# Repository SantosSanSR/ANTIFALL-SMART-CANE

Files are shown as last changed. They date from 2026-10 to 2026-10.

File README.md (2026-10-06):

# AFSC — Anti-Fall Smart Cane

An ESP32-based assistive technology prototype exploring multisensor
event detection, local feedback, and remote notifications through Telegram.

Developed in the academic context of Bionic Engineering at
Universidad Popular Autónoma del Estado de Puebla (UPAEP), Puebla, Mexico.

**Project lead:** Santiago Alejandro Santos Rosas
**Status:** Academic prototype — validation pending

## Overview

AFSC integrates motion, impact, optical pulse sensing, and passive
infrared motion detection into a walking cane prototype.

The firmware combines sensor-trigger information using a state machine
that escalates from local audible and visual feedback to remote
Telegram notifications. A user acknowledgement button supports
alert cancellation.

The project explores embedded systems, physiological instrumentation,
assistive technology, and systems-engineering documentation.

Despite the project name, AFSC does not physically prevent falls.
It investigates the detection of possible events and notification
of a designated contact.

## Main features

- Acceleration and orientation monitoring using an MPU6050.
- Impact detection using three KY-031 modules.
- Experimental optical pulse estimation using a MAX30102.
- PIR-based motion/inactivity triggering.
- Multisensor trigger aggregation and escalating alert states.
- OLED display showing system state, trigger count, and sensor information.
- Audible feedback through a buzzer.
- Visual feedback through an LED indicator.
- Wi-Fi connectivity and Telegram notifications.
- User acknowledgement/cancellation button.
- Serial diagnostics and sensor initialization checks.

## Hardware

| Component | Quantity | Role |
|---|---:|---|
| ESP32-WROOM-32 development board | 1 | Processing and Wi-Fi communication |
| MPU6050 | 1 | Acceleration and orientation sensing |
| MAX30102 | 1 | Experimental optical pulse sensing |
| KY-031 | 3 | Impact-trigger inputs |
| HW-456 / SR505 mini PIR | 1 | Motion-trigger input |
| SSD1306 OLED, 128 × 64 | 1 | System feedback |
| Buzzer | 1 | Audible feedback |
| LED indicator | 1 | Visual feedback |
| Push button | 1 | User acknowledgement |
| Battery and power circuitry | As required | Portable power |
| Cane frame and wiring | As required | Mechanical integration |

Verify the electrical specifications of the actual modules before assembly.
The GPIO table below is a firmware mapping, not a complete wiring guide.

## Firmware GPIO mapping

| Signal | ESP32 GPIO |
|---|---:|
| Impact sensor 1 | 27 |
| Impact sensor 2 | 26 |
| Impact sensor 3 | 25 |
| Buzzer | 14 |
| Acknowledgement button | 2 |
| PIR input | 33 |
| LED indicator | 13 |
| I²C SDA | 21 |
| I²C SCL | 22 |

The button wiring and active logic level must be checked before use:
the design report contains inconsistent descriptions of the pull-up
configuration and pressed state.

## System architecture

```text
MPU6050 ────────────────┐
3 × KY-031 ────────────┤
MAX30102 ──────────────┼── ESP32 ── State machine ── OLED / LED / Buzzer
PIR motion input ──────┤                  │
Acknowledgement button┘                  └── Wi-Fi ── Telegram
```

### Trigger aggregation

The firmware aggregates four trigger categories:

1. Impact.
2. Motion/orientation-based possible fall event.
3. Optical pulse signal availability.
4. PIR-based absence of detected motion.

The three impact modules contribute to one impact category;
they are not counted as three independent alert categories.

| Active trigger categories | Firmware state |
|---:|---|
| 0 | `NORMAL` |
| 1 | `ALERT_1` |
| 2 | `ALERT_2` |
| 3 | `ALERT_3` |
| 4 | `CRITICO` |

Additional states include `CALIBRATING` and `CANCELLED`.

A high trigger count is a prototype classification rule.
It does not establish that a person has fallen or is experiencing
a medical emergency.

## Software dependencies

The firmware shown in the design report uses:

- Arduino framework with ESP32 board support.
- `Wire`
- `WiFi`
- `WiFiClientSecure`
- `UniversalTelegramBot`
- `MPU6050_tockn`
- `Adafruit_GFX`
- `Adafruit_SSD1306`
- `MAX30105` and `heartRate.h` from the SparkFun MAX3010x library.
- ESP32 system utilities through `esp_system.h`.

Dependency and board-package versions should be recorded after
a successful build. Third-party dependencies retain their own licenses.

## Getting started

1. Install Arduino IDE and ESP32 board support.
2. Install the required libraries and their dependencies.
3. Open the project firmware.
4. Review the wiring and verify module voltage compatibility.
5. Configure Wi-Fi and Telegram credentials locally.
6. Select the correct ESP32 board and serial port.
7. Compile and upload the firmware.
8. Open the Serial Monitor at 115200 baud.
9. Keep the device stationary during initialization and calibration.
10. Perform controlled bench tests before any demonstration.

Do not test falls by asking a person to fall.

### Credentials

Never commit real Wi-Fi passwords, Telegram bot tokens,
or personal chat identifiers.

For publication, replace embedded credentials with placeholders.
A recommended improvement is to move credentials into a local
`secrets.h` file and publish only `secrets.example.h`.

Creating these files alone does not change the firmware:
the sketch must be updated to include and use the local configuration.

## Validation status

The design report documents the architecture, firmware, and a test plan.
It does not establish quantified clinical or real-world performance.

Planned evaluation includes:

- Individual sensor checks.
- Controlled motion and impact simulations.
- State-machine transition testing.
- Acknowledgement-button testing.
- Telegram delivery and failure handling.
- Response-time measurement.
- Power consumption and battery-runtime testing.
- Mechanical integration checks.
- Repeatability and false-alert assessment.

Battery autonomy, detection accuracy, environmental resistance,
and notification latency must be treated as targets until measured
and supported by test records.

## Known limitations and review items

- Cane motion is not equivalent to body motion; dropping the cane
  may resemble a fall event.
- PIR activity is not a direct measurement of the user's mobility
  or consciousness.
- Optical pulse estimates depend on contact and signal quality.
- Loss of optical signal is not evidence of a cardiac emergency.
- The firmware does not demonstrate validated abnormal-heart-rate
  detection.
- Remote notifications depend on Wi-Fi, internet access, and Telegram.
- Blocking delays and network requests require latency evaluation.
- The report's firmware uses `client.setInsecure()`, disabling TLS
  certificate verification; this must be reviewed before deployment.
- The inactivity threshold differs between the report's test plan
  and the firmware.
- Button polarity and cancellation behavior require verification.
- An ultrasonic obstacle sensor is mentioned as a requirement,
  but is not implemented in the firmware shown in the report.
- No clinical validation, IP rating, or certified emergency-response
  performance is claimed.

## Documentation and demonstration

The project follows a PDR/CDR-style documentation process covering:

- Requirements.
- System architecture.
- Hardware selection.
- Firmware design.
- Integration.
- Test planning.
- Safety considerations.

Prototype demonstration:
[Watch the circuit demonstration](https://youtu.be/Oy1licVQWoQ)

## Safety notice

This is an academic and research prototype, not a clinically
validated medical device.

It must not be relied upon for diagnosis, treatment, fall prevention,
patient monitoring, or emergency response. It does not replace
a caregiver, certified assistive equipment, or emergency services.

## Authorship and acknowledgement

Project lead: Santiago Alejandro Santos Rosas.

When referencing this work, credit Santiago Alejandro Santos Rosas,
identify AFSC — Anti-Fall Smart Cane, and link to this repository.

Suggested acknowledgement:

> Based on AFSC — Anti-Fall Smart Cane, led by Santiago Alejandro
> Santos Rosas. Adaptations are the responsibility of their authors
> and do not imply endorsement by the original project lead.

Contributors and supervisors must also be credited for their actual
contributions. Project leadership does not, by itself, establish
exclusive ownership of every repository asset.

## Licensing

Original firmware is provided under the PolyForm Noncommercial
License 1.0.0. See `LICENSE`.

Original report text, photographs, and explanatory documentation
are provided under Creative Commons Attribution-NonCommercial
4.0 International. See `LICENSE-DOCUMENTATION.md`.

Third-party software and materials retain their original licenses.
Hardware manufacturing and patent rights are not granted by the
documentation license.

Commercial permissions outside these licenses require a separate
written agreement from the relevant rights holder(s).

These are source-available, noncommercial terms; this project is not
described as open source.

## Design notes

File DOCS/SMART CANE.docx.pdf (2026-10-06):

### AFSC: ANTI-FALL SMART CANE

Critical Design Document

IET400_CDR_V1.
0
Revision 0.1

File Name: IET400_CDR_V1.0 Revision: 0.1
Effective
Date:05/08/25

Universidad Popular Autónoma del Estado de Puebla Puebla, México. 72410

## Critical Design Document

# Critical Design Document

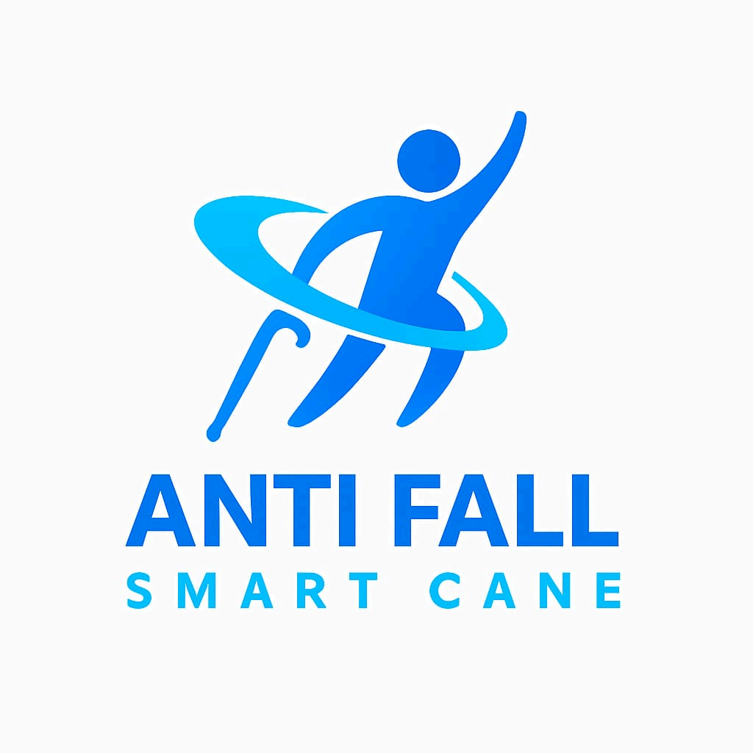
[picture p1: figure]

### AFSC: ANTI FALL SMART CANE

Critical Design Document

IET400_CDR_V1.0
Revision 0.1
Owners Document | E-Mail | Position
Leader & Owner Name | santiagoalejandro.santos @upaep.edu.mx | Project Leader

## Record of Revisions

REV | DATE | AFFECTED PAGES | DESCRIPTION OF CHANGE | AUTHOR(S)
Draft | 17/07/25 | All | Draft Release (PDR). | All
1.0 | 21/07/25 | All | PDR Final Release | All
2.0 | 23/07/25 | All | CDR 1 st Review | All
3.0 | 25/07/25 | All | CDR Final Release | All

### SMART CANE

Critical Design Document

Revision 0.1

### Table of Contents

### SMART CANE

Critical Design Document

Revision 0.1

## LIST OF FIGURES

Figure 1. System Block Diagram Figure 2. ESP32 Wiring Diagram with Sensors
Figure 3. Main Program Flowchart Figure 4. MPU6050 Fall Detection Logic
Figure 5. MAX30102 Heart Rate Evaluation Flow
Figure 6. PIR Inactivity Detection Flow Figure 7. Telegram Alert Message Example
Figure 8. OLED Display Interface

## LIST OF TABLES

Table 1. Sensor Specifications and Characteristics Table 2. ESP32 GPIO Pin Assignments
Table 3. Trigger Conditions and Thresholds
Table 4. System State Definitions
Table 5. WiFi and Telegram Configuration Parameters Table 6. Power Consumption Estimates
Table 7. Heart Rate Interpretation Ranges
Table 8. Component Cost Breakdown

### SMART CANE

Critical Design Document

Revision 0.1

### 1.0 Document Purpose

The purpose of this document is to describe the design, development, and implementation of a smart fall detection system integrated into a walking stick. The system utilises multiple sensors to monitor potential fall events in elderly users and sends real-time alerts via Telegram. This report outlines the system architecture, sensor integration, firmware logic, testing procedures, and relevant results, demonstrating the reliability and usability of the proposed assistive device.

### 1.1 Document Scope

This document covers the functional and technical aspects of the Smart Cane fall detection system. It includes a detailed description of the hardware components, sensor integration, firmware structure, user interaction logic, and communication protocols. The scope is limited to the prototype development phase, focusing on fall detection, user notification through Telegram, and initial testing under controlled conditions. Future enhancements such as GPS integration, long-range communication, and improved power management are not included in this version.

### 1.2 Change Control and Update Procedures

Changes to this PDR document shall only be made after approval by designated representatives. Document change requests should be sent to an official team member to be submitted to a higher rank and finally to be accepted by the Project Manager.

## 2.0 Reference Documents

- InvenSense. (2013, agosto 19). MPU‑6000 and MPU‑6050 Product Specification (Rev. 3.4). InvenSense.
Recuperado | de
https://invensense.tdk.com/wp-content/uploads/2015/02/MPU-6000-Datasheet1.pdf
- Adafruit Industries. (2019, noviembre 6). MPU‑6050 6‑axis Accelerometer and Gyro [Hoja técnica].
Recuperado | de
https://cdn-learn.adafruit.com/downloads/pdf/mpu6050-6-axis-accelerometer-and-gyro.pdf

### SMART CANE

Critical Design Document

Revision 0.1

- Maxim Integrated (ahora parte de Analogue Devices). (2018, octubre). MAX30102: High-Sensitivity Pulse Oximeter and Heart-Rate Sensor [Datasheet, Rev. 1].
Recuperado | de
https://www.analog.com/media/en/technical-documentation/data-sheets/max30102.pdf
- DFRobot. (2021, junio 21). Gravity: MAX30102 Heart Rate and Oximeter Sensor Module Wiki.
Recuperado | de
https://wiki.dfrobot.com/SKU_SEN0518_Gravity_MAX30102_Heart_Rate_and_Oximeter_Sensor
- Joy‑IT. (2017, junio 16). KY‑031 Knock‑Sensor Module Datasheet.
Recuperado | de
https://eclass.uth.gr/modules/document/file.php/E-CE_U_269/Sensors/Sensors_%20Datasheets/KY-031-Joy-IT.pdf

### SMART CANE

Critical Design Document

Revision 0.1

## 3.0 Concept of Operation

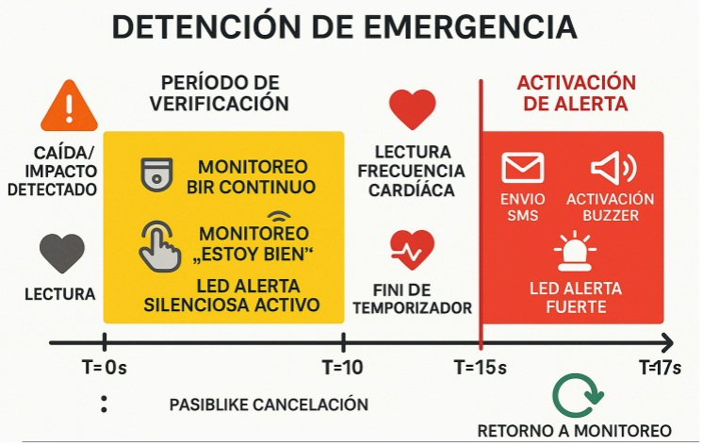
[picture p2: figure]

The intelligent cane system operates as a wearable safety device designed to monitor the user's condition and environment, providing real-time alerts in critical situations. It integrates multiple sensors—including impact detectors (KY-031), a motion sensor (MPU6050), a heart rate monitor (MAX30102), and a PIR motion detector (HW-456-SR505)—to detect falls, impacts, heart rate anomalies, and prolonged inactivity. The system processes sensor data continuously, incrementing a trigger count based on active alerts. When the trigger count reaches specific thresholds (1 for ALERT_1, 2 for ALERT_2, 3 for ALERT_3, and 4 for CRITICO), it escalates the response: from brief buzzer signals to sending Telegram notifications. In the CRITICO state (4 triggers), it sends five consecutive "Alerta crítica\nTriggers: 4" messages and activates a buzzer, giving the user 10 seconds to press a button. If pressed, it sends "Falsa alarma, todo bien" to cancel the alert; otherwise, it resets after the timeout. The OLED display provides visual feedback, showing the current state and sensor status, ensuring the user and caregivers are informed. WiFi connectivity enables remote notifications, making it a robust solution for elderly or at-risk individuals.

### SMART CANE

Critical Design Document

Revision 0.1

## 4.0 Project Summary

### 4.1 Goal

The Smart Cane is designed to ensure that elderly individuals or people with disabilities are never left alone, offering a fall detection and emergency alert system that provides continuous monitoring and support. By integrating sensors such as impact detection (KY-031), motion tracking (MPU6050), heart rate monitoring (MAX30102), and inactivity detection (PIR) on a walking cane, the device detects critical incidents like falls or health emergencies in real time. Equipped with a buzzer for immediate audible alerts, an LED for visual feedback, and an ESP32 module for wireless notifications to a designated Telegram chat, it enables remote oversight by caregivers or family members. The OLED display provides status updates, while an “I’m OK” button helps manage false alarms. This solution aims to offer freedom and security by keeping users connected to their support network, ensuring timely assistance without compromising their independence.

### 4.2 Objectives

- Accurate Fall Detection: Achieve precise identification of falls by analysing a combination of acceleration and orientation data from the MPU6050, ensuring reliable detection even in complex movement scenarios.
- Real-Time Heart Rate Monitoring: Continuously monitor heart rate using the MAX30102 sensor, triggering alerts for abnormal readings (outside 40-180 BPM) or when the sensor disconnects, indicating potential health risks.
- Prolonged Inactivity Detection: Utilise the PIR sensor to detect extended periods of immobility (beyond 4 seconds), activating alerts to address situations where the user may be incapacitated or unable to respond.
- Minimise False Positives: Implement a multi-trigger validation system that requires confirmation across multiple sensors (up to 4 triggers for CRITICO state) and include an “I’m OK” button to allow users to cancel false alarms, enhancing system accuracy and reducing unnecessary notifications.
- Real-Time Alert Transmission: Leverage Wi-Fi connectivity via the ESP32 to send immediate, detailed alerts to a Telegram chat, ensuring caregivers or family members are promptly informed of emergencies with specific trigger details.
- Status and Vital Signs Display: Present real-time system status, including the current state (e.g., NORMAL, CRITICAL), trigger count, and vital signs (e.g., heart rate) on an OLED screen, providing users and caregivers with clear, at-a-glance information.
- Reliable, Low-Cost, Non-Intrusive Support: Develop a robust, affordable device that integrates seamlessly into daily life as a walking aid, offering a non-invasive monitoring solution that supports caregivers and family members by delivering actionable insights.

### SMART CANE

Critical Design Document

Revision 0.1

## 5.0 Requirements

The Smart Cane system shall meet the following requirements:

Functional Requirements:

- Fall Detection: Swiftly detect falls using the MPU6050 accelerometer and gyroscope, identifying incidents within moments to ensure immediate awareness.
- Heart Rate Monitoring: Track heart rate accurately with the MAX30102 sensor, providing reliable updates to flag potential health concerns as they arise.
- Inactivity Detection: Recognise prolonged inactivity using the PIR sensor, alerting caregivers to situations where the user may need assistance.
- Telegram Alerts: Send instant alerts to predefined contacts via Telegram, keeping caregivers informed of critical events like falls or health issues with minimal delay.
- Real-Time Display: Continuously update heart rate, system status, and alerts on a 0.96-inch OLED display, offering users and caregivers a clear, live view of the patient’s condition.
- Obstacle Awareness: Detect nearby obstacles using an ultrasonic sensor, enhancing user safety by preventing collisions during movement.
- Performance Requirements:
- Extended Operation: Operate reliably for over 12 hours on a single battery charge, ensuring uninterrupted support throughout the day.
- Continuous Updates: Refresh sensor data and display information every 1 second, maintaining a seamless flow of real-time insights for both user and caregiver.
- Environmental Requirements:
- Versatile Conditions: Perform effectively in a wide range of temperatures and light rain, making it a dependable companion for indoor and outdoor use.
- Durable Design: Built to withstand everyday environmental challenges, ensuring consistent performance in varied settings.
- Safety Requirements:
- User-Friendly Design: Crafted with comfortable, safe materials for prolonged contact, prioritising the well-being of the user.
- Secure Operation: Engineered to provide a stable and safe experience, focusing on the user’s peace of mind.

### SMART CANE

Critical Design Document

Revision 0.1

## 6.0 Project Schedule

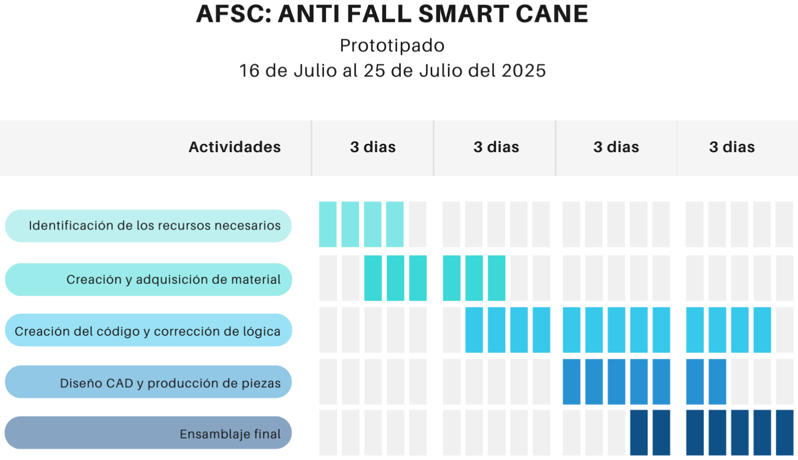
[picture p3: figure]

## 7.0 Materials, Equipment & Total Cost

### 7.1 Microcontroller(s)

The ESP32-WROOM-32 module was selected for the Smart Cane due to its dual-core processor, integrated Wi-Fi/Bluetooth connectivity, and 38 GPIO pins, enabling efficient sensor integration (MPU6050, MAX30102, KY-031, PIR) and real-time communication. Operating at 3.3V with a clock speed of up to 240 MHz, it ensures rapid processing for fall detection and health monitoring. The ESP32 was chosen over the Arduino Uno for its built-in wireless capabilities (eliminating the need for extra

### SMART CANE

Critical Design Document

Revision 0.1

shields), higher processing power (240 MHz vs. 16 MHz), and lower cost (~$5 vs. $20), supporting continuous caregiver updates and the project’s 12-hour battery life goal. Its extensive community support further enhances development flexibility, making it an ideal, cost-effective choice for reliable remote monitoring.

### 7.2 Sensors and Actuators

Table 1: Sensor Specifications and Characteristics
Sensor | Image | Function | Operating | Error
MPU6050 | | Fall detection (accelerometer, gyroscope) | 3.3V | ±3%
MAX30102 | | Heart rate monitoring | 1.8V-3.3V | ±5 bpm

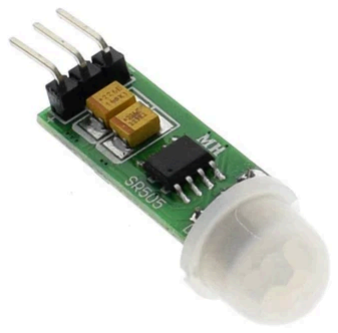
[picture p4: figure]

Mini PIR Sensor | | Inactivity detection | 3.3V-5V | N/A

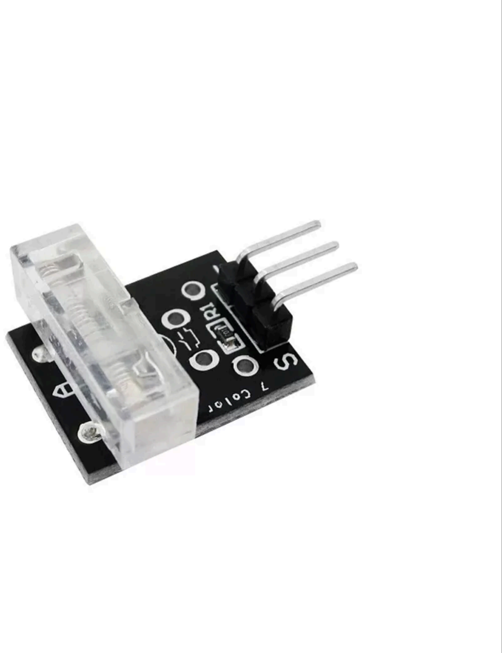
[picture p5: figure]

KY-031 | | Impact detection | 5V | ±3 mm

### SMART CANE

Critical Design Document

Revision 0.1

The sensors selected for the Smart Cane—MPU6050, MAX30102, KY-031, and PIR HW-456-SR505—are ideal for this project due to their combination of accuracy, compatibility, and specific functionalities that align with the objectives of fall detection, health monitoring, and safety. The MPU6050, with its integrated accelerometer and gyroscope, offers fast and reliable fall detection by analysing real-time acceleration and orientation, which is essential in critical emergencies. The MAX30102 stands out for its ability to measure heart rate with high accuracy (±5 bpm) using infrared light technology, enabling continuous monitoring and anomaly alerts, making it ideal for the health of vulnerable users. The KY-031, as an impact sensor, detects physical collisions with adjustable sensitivity, complementing fall detection, while the PIR HW-456-SR505 identifies prolonged inactivity with low power consumption, ensuring timely alerts without draining the battery. These sensors, integrated with the ESP32, fit perfectly into the portable and low-cost design of the cane, providing a robust, non-invasive, and efficient system to support users and caregivers effectively.

### 7.3 Other Components Required

Components | Image | Function | Operating | Error

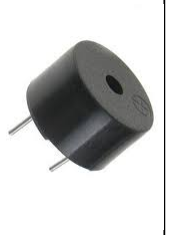
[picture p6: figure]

Buzzer | | Generate audible warning signals when an emergency is detected. | The piezoelectric buzzer works by vibrating a piezoelectric disc, which, when an electrical signal (often PWM) is applied, generates audible sound waves. It is activated by applying a DC voltage (usually 3.3V or 5V).

N/A

### SMART CANE

Critical Design Document

Revision 0.1

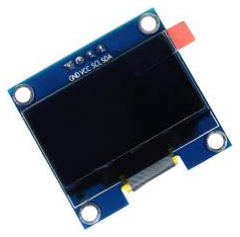
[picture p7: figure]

Pantalla oled
Display relevant
system
information such
as patient status,
heart rate (BPM),
alerts, and status
messages.

It uses OLED
(organic
light-emitting
diode) technology
to display text and
icons. It does not
require
backlighting and
communicates
with the
microcontroller
(ESP32 or
Arduino) via the
I2C interface
(SDA/SCL).

N/A

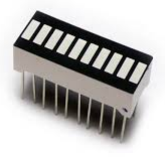
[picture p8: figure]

Barra led | Provide a visual warning signal with different flashing modes depending on the emergency level or number of events (triggers). | When voltage is applied to the LED anode through a limiting resistor, visible light is generated. The flashing or brightness can be controlled by code (digitalWrite or PWM). . | N/A

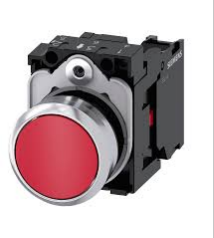
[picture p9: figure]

Boton | Allow the user to cancel an alert in case of a false positive or to confirm that they are okay before an emergency is triggered. | It is a mechanical switch that, when pressed, closes a circuit by sending a digital signal (usually LOW or HIGH) to the microcontroller. It | N/A

SMART CANE Critical Design Document | Revision 0.1
| . | is used in conjunction with a pull-up or pull-down resistor.

### 7.4 Total Cost of System

Table 2: Component Cost Breakdown
Component | Individual Cost ($) | Quantity
ESP32-WROOM-32 | 125 MXN | 1
MPU6050 | 75 MXN | 1
MAX30102 | 170 MXN | 1
Mini PIR Sensor | 57 MXN | 1
KY-031 | 61 MXN | 3
OLED Display | 126 MXN | 1
Li-Po Battery 3.7v | 150 MXN | 1
CN6009 | 55 MXN | 1
Buzzer | 35 MXN | 1
Cane Frame | 250 MXN | 1
Miscellaneous (wires, resistors) | 250 MXN | N/A
TOTAL | 1354 MXN

### SMART CANE

## 8.0 System Design

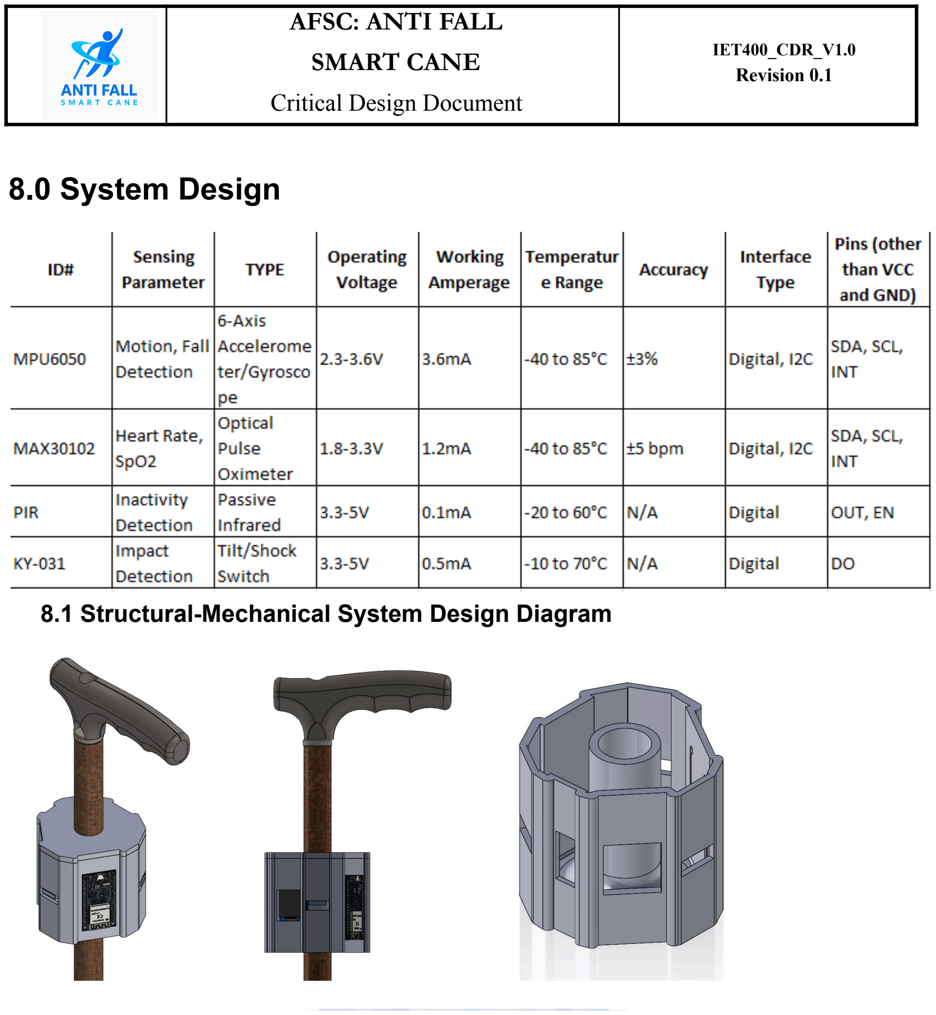
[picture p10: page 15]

Critical Design Document

Revision 0.1

### 8.1 Structural-Mechanical System Design Diagram

### SMART CANE

Critical Design Document

Revision 0.1

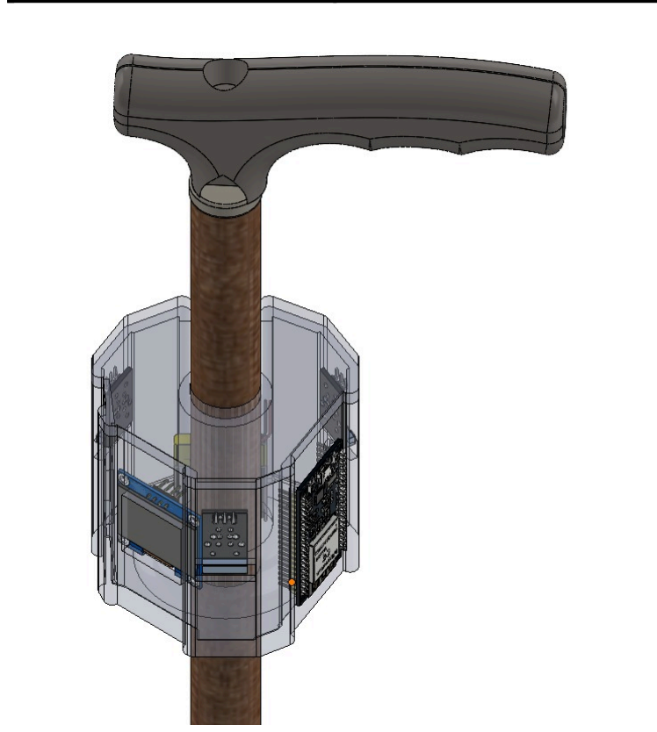
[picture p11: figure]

### 8.2 Electrical System Design Diagram

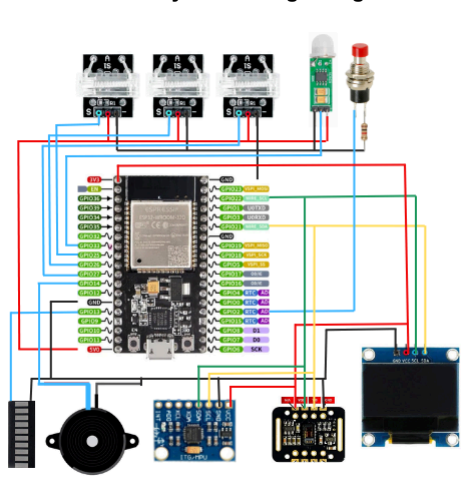
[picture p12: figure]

### SMART CANE

Critical Design Document

Revision 0.1

### 8.3 Sensor System Code

#include <Wire.h>

#include <WiFi.h>

#include <WiFiClientSecure.h> #include <UniversalTelegramBot.h> #include <MPU6050_tockn.h> #include <Adafruit_GFX.h>

#include <Adafruit_SSD1306.h> #include <MAX30105.h>

#include <heartRate.h>

#include <esp_system.h>

// Pines
#define IMPACT_PIN_1 27 // KY-031 #define IMPACT_PIN_2 26 // KY-031

#define IMPACT_PIN_3 25 // KY-031

#define BUZZER_PIN | 14 // Buzzer

#define BUTTON_PIN | 2 // Botón (pull-up externo 4.7kΩ a 3.3V, botón a GND, HIGH al

presionar)
#define PIR_PIN | 33 // Mini PIR HW-456-SR505

#define LED_PIN | 13 // Barra LED

#define SDA_PIN | 21

#define SCL_PIN | 22

// Pantalla
#define SCREEN_WIDTH 128

#define SCREEN_HEIGHT 64

#define OLED_RESET -1

Adafruit_SSD1306 display(SCREEN_WIDTH, SCREEN_HEIGHT, &Wire, OLED_RESET);

// Sensores
MPU6050 mpu(Wire);
MAX30105 particleSensor;

// Telegram
const char* ssid = "****************";
const char* password = "**************";
#define BOT_TOKEN "***************************************************" #define CHAT_ID "*********************************"

WiFiClientSecure client;
UniversalTelegramBot bot(BOT_TOKEN, client);

### SMART CANE

Critical Design Document

Revision 0.1

// Estructuras
struct SensorStatus {
bool impact = false;
bool mpu = false;
bool heart = false;
bool pir = false;
bool wifi = false;
};

struct Trigger {
bool active = false;
unsigned long time = 0;
bool latched = false; // Estado retenido temporal };

// Variables globales
SensorStatus sensors;
volatile Trigger mpuTrigger = {false, 0, false}; Trigger impactTrigger = {false, 0, false}; Trigger heartTrigger = {false, 0, false}; Trigger pirTrigger = {false, 0, false};
int triggerCount = 0;
int lastTriggerCount = 0;
unsigned long lastNotificationTime = 0;
int totalSensors = 0;
bool threeTriggerNotified = false; // Flag para 3 triggers

// Estados
enum State { CALIBRATING, NORMAL, ALERT_1, ALERT_2, ALERT_3, CRITICO, CANCELLED }; State currentState = CALIBRATING;

// MPU Parameters
const float FALL_ACCEL_THRESHOLD = 1.2;
const float ANGLE_TOLERANCE = 25.0;
const unsigned long CONFIRM_DELAY = 5000;
const unsigned long MOTION_TIMEOUT = 40000; // 40 segundos
const unsigned long CRITICO_TIMEOUT = 10000; // 10 segundos para presionar botón en estado CRITICO

// MAX30102 Parameters
const long IR_THRESHOLD = 50000;
const int BPM_MIN = 40, BPM_MAX = 180;

### SMART CANE

Critical Design Document

Revision 0.1

const byte RATE_SIZE = 4;

// PIR Parameters
const unsigned long PIR_WARMUP = 30000;
const unsigned long PIR_NO_MOTION_TIMEOUT = 4000; // 4 segundos

// Impacto Parameters
const int IMPACT_SAMPLES = 10;

// Variables MPU
float pitchCal = 0, rollCal = 0;
bool mpuCalibrated = false;
float lastAccel = 0;
unsigned long mpuAlertStartTime = 0;
enum MPUState { MPU_NORMAL, MPU_ALERT, MPU_CONFIRMED } mpuState = MPU_NORMAL;
unsigned long lastMpuUpdate = 0; // Para detectar bloqueos

// Variables BPM
byte rates[RATE_SIZE] = {0};
byte rateSpot = 0;
long lastBeat = 0;
int stableBeatAvg = 0;

// Variables de tiempo
unsigned long stateStartTime = 0; unsigned long lastUpdate = 0; unsigned long displayUpdate = 0; unsigned long ledBlinkTime = 0; unsigned long pirWarmupStart = 0; bool ledState = false;

// Variables botón
bool buttonPressed = false;
unsigned long lastButtonTime = 0;
const unsigned long DEBOUNCE_TIME = 200; int buttonReadCount = 0;

#define NOTIFICATION_COOLDOWN 60000

// Variables para mensajes temporales String tempMessage = "";
unsigned long tempMessageStart = 0;

### SMART CANE

Critical Design Document

Revision 0.1

const unsigned long TEMP_MESSAGE_DURATION = 500; // Duración para parpadeo bool tempMessageBlink = false;

// Función para mostrar texto en OLED
void displayText(String text) {
display.clearDisplay();
display.setTextSize(1);
display.setTextColor(WHITE); display.setCursor(0, 20);
display.println(text);
display.display();
}

void mostrarMensajeGrandeOLED(String mensaje) { tempMessage = mensaje;
tempMessageStart = millis();
tempMessageBlink = true;
}

void drawHeartIcon(int x, int y) {
static const unsigned char heartBitmap[] PROGMEM = { 0b00001100, 0b00110000,
0b00011110, 0b01111000,
0b00111111, 0b11111100,
0b01111111, 0b11111110,
0b01111111, 0b11111110,
0b01111111, 0b11111110,
0b00111111, 0b11111100,
0b00011111, 0b11111000,
0b00001111, 0b11110000,
0b00000111, 0b11100000,
0b00000011, 0b11000000,
0b00000001, 0b10000000,
0b00000000, 0b00000000
};
display.drawBitmap(x, y, heartBitmap, 16, 13, WHITE); }

// Setup
void setup() {
Serial.begin(115200);
Serial.println("=== Baston Inteligente V4.2.9 ==="); Serial.print("Razon de reinicio: ");

### SMART CANE

Critical Design Document

Revision 0.1

switch (esp_reset_reason()) {
case ESP_RST_POWERON: Serial.println("Power-on reset"); break; case ESP_RST_EXT: Serial.println("External reset"); break;
case ESP_RST_SW: Serial.println("Software reset"); break;
case ESP_RST_PANIC: Serial.println("Exception/Panic"); break; case ESP_RST_INT_WDT: Serial.println("Interrupt Watchdog"); break; case ESP_RST_TASK_WDT: Serial.println("Task Watchdog"); break; case ESP_RST_WDT: Serial.println("Other Watchdog"); break;
case ESP_RST_DEEPSLEEP: Serial.println("Deep Sleep reset"); break; case ESP_RST_BROWNOUT: Serial.println("Brownout reset"); break;
default: Serial.println("Unknown"); break;
}
Serial.println("Botón: Configurado en GPIO 2 con pull-up EXTERNO de 4.7kΩ a 3.3V (botón a GND, HIGH al presionar).");

pinMode(IMPACT_PIN_1, INPUT_PULLUP);
pinMode(IMPACT_PIN_2, INPUT_PULLUP);
pinMode(IMPACT_PIN_3, INPUT_PULLUP); pinMode(BUZZER_PIN, OUTPUT); pinMode(BUTTON_PIN, INPUT); pinMode(PIR_PIN, INPUT);
pinMode(LED_PIN, OUTPUT);
digitalWrite(BUZZER_PIN, LOW); digitalWrite(LED_PIN, LOW);

Wire.begin(SDA_PIN, SCL_PIN); Wire.setClock(100000);

byte oledAddress = scanI2C();
bool oledOk = false;
if (oledAddress != 0) {
if (display.begin(SSD1306_SWITCHCAPVCC, oledAddress)) { oledOk = true;
Serial.println("OLED inicializado en 0x" + String(oledAddress, HEX)); displayText("Iniciando...");
}
}
if (!oledOk) {
Serial.println("Error: OLED no inicializado"); }

checkSensors();
connectWiFi();

### SMART CANE

Critical Design Document

Revision 0.1

calibrateMPU();
totalSensors = sensors.impact + sensors.mpu + sensors.heart + sensors.pir; Serial.println("Sensores activos: " + String(totalSensors));

if (sensors.pir) {
Serial.println("Calentando PIR HW-456-SR505..."); displayText("Calentando PIR...");
pirWarmupStart = millis();
while (millis() - pirWarmupStart < PIR_WARMUP) { delay(100);
}
}

if (oledOk) {
displayText("Iniciando..."); delay(2000);
}
currentState = NORMAL;
}

// Escanear direcciones I2C
byte scanI2C() {
Serial.println("Escaneando I2C..."); byte address = 0;
for (byte addr = 1; addr < 127; addr++) { Wire.beginTransmission(addr);
if (Wire.endTransmission() == 0) { Serial.println("Dispositivo en 0x" + String(addr, HEX)); if (addr == 0x3C || addr == 0x3D) {
address = addr;
} else if (addr == 0x57) {
sensors.heart = true;
Serial.println("MAX30102 detectado en 0x57"); }
}
}
if (address == 0) {
Serial.println("No se encontro OLED en I2C"); }
return address;
}

// Verificación de sensores

### SMART CANE

Critical Design Document

Revision 0.1

void checkSensors() {
Serial.println("Verificando sensores...");
int impactReadings[3] = { digitalRead(IMPACT_PIN_1), digitalRead(IMPACT_PIN_2), digitalRead(IMPACT_PIN_3) };
sensors.impact = (impactReadings[0] == HIGH && impactReadings[1] == HIGH && impactReadings[2] == HIGH);
Serial.println("Impacto (KY-031): " + String(sensors.impact ? "OK" : "No detectado")); Serial.println(" Pin 27: " + String(impactReadings[0]));
Serial.println(" Pin 26: " + String(impactReadings[1]));
Serial.println(" Pin 25: " + String(impactReadings[2]));

mpu.begin();
Wire.beginTransmission(0x68);
Wire.write(0x75);
Wire.endTransmission(false);
Wire.requestFrom(0x68, 1);
sensors.mpu = (Wire.available() && Wire.read() == 0x68); Serial.println("MPU6050: " + String(sensors.mpu ? "OK" : "No detectado"));

if (sensors.heart && particleSensor.begin(Wire, I2C_SPEED_FAST)) { particleSensor.setup();
particleSensor.setPulseAmplitudeRed(0x0A); particleSensor.setPulseAmplitudeGreen(0); Serial.println("MAX30102: OK");
} else {
sensors.heart = false;
Serial.println("MAX30102: No detectado"); }

sensors.pir = true;
Serial.println("PIR (HW-456-SR505): OK"); Serial.println(" PIR Pin 33: " + String(digitalRead(PIR_PIN))); }

// Conexión WiFi
void connectWiFi() {
Serial.print("Conectando WiFi...");
WiFi.begin(ssid, password);
int attempts = 0;
while (WiFi.status() != WL_CONNECTED && attempts++ < 20) { delay(500);
Serial.print(".");
}

### SMART CANE

Critical Design Document

Revision 0.1

sensors.wifi = WiFi.status() == WL_CONNECTED; Serial.println(sensors.wifi ? "OK" : "Fallo");
if (sensors.wifi) {
client.setInsecure();
bot.sendMessage(CHAT_ID, "SMART CANE INIT", ""); }
displayText(sensors.wifi ? "WiFi OK" : "WiFi fallo"); delay(2000);
}

// Calibración MPU
void calibrateMPU() {
if (!sensors.mpu) return;
displayText("Calibrando MPU..."); Serial.println("Calibrando MPU..."); float pitchSum = 0, rollSum = 0; for (int i = 0; i < 20; i++) { mpu.update();
pitchSum += mpu.getAngleX(); rollSum += mpu.getAngleY(); delay(100);
}
pitchCal = pitchSum / 20;
rollCal = rollSum / 20;
mpuCalibrated = true;
Serial.println("MPU calibrado: PitchCal=" + String(pitchCal, 2) + ", RollCal=" + String(rollCal, 2)); }

// Loop principal
void loop() {
unsigned long currentTime = millis(); readSensors();
checkButton();
updateTriggers(currentTime); handleState(currentTime);
updateDisplay();
updateLED(currentTime);
if (currentTime - lastUpdate > 2000) { printDebugInfo();
lastUpdate = currentTime;
}
delay(20);
}

### SMART CANE

Critical Design Document

Revision 0.1

// Lectura de sensores
void readSensors() {
if (sensors.impact) readImpact();
if (sensors.mpu && mpuCalibrated) readMPU();
if (sensors.heart) readHeart();
if (sensors.pir && millis() - pirWarmupStart > PIR_WARMUP) readPIR(); }

void readImpact() {
int readings[3] = { HIGH, HIGH, HIGH };
for (int i = 0; i < IMPACT_SAMPLES; i++) { readings[0] &= digitalRead(IMPACT_PIN_1); readings[1] &= digitalRead(IMPACT_PIN_2); readings[2] &= digitalRead(IMPACT_PIN_3);
delay(2);
}
if ((readings[0] == LOW || readings[1] == LOW || readings[2] == LOW) && !impactTrigger.latched) {
impactTrigger.active = true;
impactTrigger.time = millis();
impactTrigger.latched = true; // Activar retención Serial.println("Impacto detectado (KY-031) - Latch activado"); sendTelegramNotification();
}
// Ajuste a 60 segundos para impacto
if (impactTrigger.latched && (millis() - impactTrigger.time > 60000)) { impactTrigger.active = false;
impactTrigger.latched = false;
Serial.println("Impacto - Timeout alcanzado (60s), latch desactivado"); }
}

void readMPU() {
mpu.update();
float accX = mpu.getAccX();
float accY = mpu.getAccY();
float accZ = mpu.getAccZ();
float currentAccel = sqrt(accX * accX + accY * accY + accZ * accZ); float deltaAccel = abs(currentAccel - lastAccel);
lastAccel = currentAccel;
float pitch = mpu.getAngleX();
float roll = mpu.getAngleY();

### SMART CANE

Critical Design Document

Revision 0.1

// Detectar y reiniciar si el MPU está bloqueado
if (accX == 0.00 && accY == 0.00 && accZ == 0.00 && (millis() - lastMpuUpdate > 1000)) { Serial.println("MPU bloqueado detectado, reiniciando...");
mpu.begin();
mpuCalibrated = false;
calibrateMPU();
return;
}
lastMpuUpdate = millis();

Serial.println("MPU - Raw Acc: " + String(accX, 2) + ", " + String(accY, 2) + ", " + String(accZ, 2) + " Delta: " + String(deltaAccel, 2));
if (deltaAccel > FALL_ACCEL_THRESHOLD && mpuState == MPU_NORMAL && !mpuTrigger.latched) {
Serial.println("MPU - Condición de caída detectada (subtrigger)");
mpuState = MPU_ALERT;
mpuAlertStartTime = millis();
mpuTrigger.latched = true; // Activar estado retenido mpuTrigger.time = millis();
digitalWrite(BUZZER_PIN, HIGH);
mostrarMensajeGrandeOLED("CAÍDA");
} else if (mpuState == MPU_ALERT && millis() - mpuAlertStartTime >= CONFIRM_DELAY) { Serial.println("MPU - Evaluando confirmación");
float pitchDiff = abs(pitch - pitchCal);
float rollDiff = abs(roll - rollCal);
Serial.println("MPU - PitchDiff: " + String(pitchDiff, 2) + " RollDiff: " + String(rollDiff, 2)); if ((pitchDiff > ANGLE_TOLERANCE || rollDiff > ANGLE_TOLERANCE)) {
mpuState = MPU_CONFIRMED;
mpuTrigger.active = true; // Activar trigger general tras confirmación mpuTrigger.latched = false; // Resolver el estado retenido mostrarMensajeGrandeOLED("CONFIRMADA");
Serial.println("MPU - Caída confirmada. PitchDiff: " + String(pitchDiff, 2) + " RollDiff: " + String(rollDiff, 2) + " Trigger: " + String(mpuTrigger.active)); } else {
mpuState = MPU_NORMAL; // Si no se confirma, volver a normal mpuTrigger.latched = false; // Resolver el estado retenido digitalWrite(BUZZER_PIN, LOW);
}
}
// Mantener trigger activo durante 40 segundos tras confirmación
if (mpuTrigger.active && (millis() - mpuTrigger.time > MOTION_TIMEOUT)) { mpuState = MPU_NORMAL;

### SMART CANE

Critical Design Document

Revision 0.1

mpuTrigger.active = false;
digitalWrite(BUZZER_PIN, LOW);
Serial.println("MPU - Regresó a normal (40s). Trigger: " + String(mpuTrigger.active)); }
}

void readHeart() {
long irValue = particleSensor.getIR();
Serial.println("Heart - IR: " + String(irValue) + " Beat: " + String(checkForBeat(irValue))); if (irValue < 5000) {
for (byte x = 0; x < RATE_SIZE; x++) rates[x] = 0;
stableBeatAvg = 0;
heartTrigger.active = true;
heartTrigger.time = millis();
heartTrigger.latched = true; // Activar retención
Serial.println("Sin señal en MAX30102 (IR=" + String(irValue) + ")"); sendTelegramNotification();
} else if (checkForBeat(irValue) && irValue > 5000) {
long delta = millis() - lastBeat;
lastBeat = millis();
if (delta > 250) {
float beatsPerMinute = 60000 / delta;
if (beatsPerMinute >= BPM_MIN && beatsPerMinute <= BPM_MAX) { rates[rateSpot++] = (byte)beatsPerMinute;
rateSpot %= RATE_SIZE;
stableBeatAvg = 0;
for (byte x = 0; x < RATE_SIZE; x++) { stableBeatAvg += rates[x];
}
stableBeatAvg /= RATE_SIZE;
Serial.println("Heart - New BPM: " + String(stableBeatAvg)); }
}
} else if (irValue > IR_THRESHOLD && heartTrigger.latched) { heartTrigger.active = false;
heartTrigger.latched = false;
}
}

void readPIR() {
static unsigned long lastMotion = 0; int pirState = digitalRead(PIR_PIN); if (pirState == HIGH) {

### SMART CANE

Critical Design Document

Revision 0.1

lastMotion = millis();
if (pirTrigger.latched) {
pirTrigger.active = false;
pirTrigger.latched = false;
Serial.println("Movimiento detectado (HW-456-SR505) - Latch desactivado"); }
} else if (millis() - lastMotion > PIR_NO_MOTION_TIMEOUT && !pirTrigger.latched) { pirTrigger.active = true;
pirTrigger.time = millis();
pirTrigger.latched = true; // Activar retención
Serial.println("Sin movimiento por 4s (HW-456-SR505) - Latch activado"); sendTelegramNotification();
}
}

// Verificación del botón
void checkButton() {
int v_state = digitalRead(BUTTON_PIN);
buttonReadCount++;
Serial.println("Botón (GPIO 2) lectura #" + String(buttonReadCount) + ": Pin=" + String(v_state));

if (v_state == HIGH && millis() - lastButtonTime > DEBOUNCE_TIME) {
buttonPressed = true;
Serial.println("PULSADO en estado " + getStateName(currentState));
lastButtonTime = millis();
}
delay(10);
}

// Enviar notificación de Telegram
void sendTelegramNotification() {
if (!sensors.wifi) {
Serial.println("No hay conexión WiFi, intentando reconectar..."); connectWiFi();
if (!sensors.wifi) {
Serial.println("Reconexión WiFi fallida, notificación no enviada"); return;
}
}
if (triggerCount >= 2 && lastTriggerCount < 2) {
String message = "🟢 ALERTA NIVEL 1 POSIBLE CAIDA DETECTADA\nTriggers: " + String(triggerCount);
if (sensors.impact && impactTrigger.active) message += "\n- Impacto";

### SMART CANE

Critical Design Document

Revision 0.1

if (sensors.mpu && mpuTrigger.active) message += "\n- Caida";
if (sensors.heart && heartTrigger.active) message += "\n- BPM: Sin señal";
if (sensors.pir && pirTrigger.active) message += "\n- Sin movimiento";
bool sent = bot.sendMessage(CHAT_ID, message, "");
Serial.println("Notificación enviada: " + message + " - " + String(sent ? "Éxito" : "Fallo")); lastNotificationTime = millis();
}
// Notificación inmediata para 3 triggers
if (triggerCount == 3 && !threeTriggerNotified) {
if (sensors.wifi) {
bool sent = bot.sendMessage(CHAT_ID, "🟡 ALERTA NIVEL 2\nTriggers: 3", ""); Serial.println("Notificación 3 triggers: " + String(sent ? "Éxito" : "Fallo")); threeTriggerNotified = true; // Marcar como notificado
lastNotificationTime = millis(); // Actualizar cooldown después de enviar
}
}
// Resetear flag cuando triggers bajen de 3
if (triggerCount < 3) {
threeTriggerNotified = false;
}
// Serie de 5 mensajes para 4 triggers
if (triggerCount == 4) {
Serial.println("Entrando en modo de 5 alertas críticas por 4 triggers"); if (sensors.wifi) {
for (int i = 0; i < 5; i++) {
Serial.print("Intentando enviar alerta crítica #" + String(i + 1) + "... ");
bool sent = bot.sendMessage(CHAT_ID, "🔴 ALERTA CRITICA CAIDA CONFIRMADA PONGASE EN CONTACTO CON SU PACIENTE\nTriggers: 4", ""); Serial.println(sent ? "Éxito" : "Fallo");
if (!sent) {
Serial.println("Fallo en el intento #" + String(i + 1) + ", intentando reconectar..."); connectWiFi();
if (sensors.wifi) {
sent = bot.sendMessage(CHAT_ID, "🔴 ALERTA CRITICA CAIDA CONFIRMADA PONGASE EN CONTACTO CON SU PACIENTE \nTriggers: 4", ""); Serial.println(sent ? "Reintento exitoso" : "Reintento fallido");
}
}
delay(300); // Aumentar retraso para estabilidad
}
lastNotificationTime = millis(); // Respetar cooldown después de la serie } else {
Serial.println("WiFi no disponible para enviar alertas críticas");

### SMART CANE

Critical Design Document

Revision 0.1

}
}
}

// Actualización de triggers
void updateTriggers(unsigned long currentTime) {
int prevTriggerCount = triggerCount;
triggerCount = (sensors.impact && impactTrigger.active) + (sensors.mpu && mpuTrigger.active) + (sensors.heart && heartTrigger.active) + (sensors.pir && pirTrigger.active);

if (triggerCount >= 2 && prevTriggerCount < 2) { sendTelegramNotification();
}
lastTriggerCount = triggerCount;
}

// Manejo de estados
void handleState(unsigned long currentTime) { State newState = NORMAL;
if (triggerCount == 1) newState = ALERT_1; else if (triggerCount == 2) newState = ALERT_2; else if (triggerCount == 3) newState = ALERT_3; else if (triggerCount == 4) newState = CRITICO;

if (newState != currentState) {
stateStartTime = currentTime;
currentState = newState;
Serial.println("Estado cambiado a: " + getStateName(currentState)); if (currentState == ALERT_1) {
digitalWrite(BUZZER_PIN, HIGH);
delay(100);
digitalWrite(BUZZER_PIN, LOW); } else if (currentState == ALERT_2) { digitalWrite(BUZZER_PIN, HIGH); delay(100);
digitalWrite(BUZZER_PIN, LOW); delay(100);
digitalWrite(BUZZER_PIN, HIGH); delay(100);
digitalWrite(BUZZER_PIN, LOW); } else if (currentState == ALERT_3) {

### SMART CANE

Critical Design Document

Revision 0.1

digitalWrite(BUZZER_PIN, HIGH); delay(300);
digitalWrite(BUZZER_PIN, LOW);
} else if (currentState == CRITICO) { digitalWrite(BUZZER_PIN, HIGH); mostrarMensajeGrandeOLED("CRITICO"); }
}

switch (currentState) {
case ALERT_1:
case ALERT_2:
if (currentTime - stateStartTime > MOTION_TIMEOUT) { resetTriggers();
currentState = NORMAL;
}
break;
case ALERT_3:
if (buttonPressed) {
resetTriggers();
currentState = CANCELLED;
if (sensors.wifi) bot.sendMessage(CHAT_ID, "🔵 Paciente oprimió botón de seguridad, falsa alarma, pongase en contacto con su paciente para confirmar su seguridad", ""); }
break;
case CRITICO:
if (buttonPressed) {
Serial.println("Botón presionado en CRITICO, enviando notificación"); resetTriggers();
currentState = CANCELLED;
if (sensors.wifi) bot.sendMessage(CHAT_ID, "🔵 Paciente oprimió botón de seguridad, falsa alarma, pongase en contacto con su paciente para confirmar su seguridad", ""); } else if (currentTime - stateStartTime > CRITICO_TIMEOUT) {
Serial.println("Timeout de 10s alcanzado en CRITICO, enviando notificaciones"); sendTelegramNotification();
resetTriggers();
currentState = NORMAL;
}
break;
case CANCELLED:
if (currentTime - stateStartTime > 3000) { currentState = NORMAL;
digitalWrite(BUZZER_PIN, LOW);

### SMART CANE

Critical Design Document

Revision 0.1

}
break;
}
buttonPressed = false;
}

void resetTriggers() {
impactTrigger.active = false; impactTrigger.latched = false; mpuTrigger.active = false; mpuTrigger.latched = false; heartTrigger.active = false; heartTrigger.latched = false; pirTrigger.active = false; pirTrigger.latched = false; triggerCount = 0;
lastTriggerCount = 0;
mpuState = MPU_NORMAL;
threeTriggerNotified = false; // Resetear flag al cancelar digitalWrite(BUZZER_PIN, LOW);
}

// Actualización LED
void updateLED(unsigned long currentTime) { unsigned long interval;
switch (triggerCount) {
case 0: digitalWrite(LED_PIN, LOW); return; case 1: interval = 1000; break;
case 2: interval = 500; break;
case 3: interval = 250; break;
case 4: interval = 125; break; // Añadido para 4 triggers default: digitalWrite(LED_PIN, HIGH); return;
}
if (currentTime - ledBlinkTime > interval) {
ledState = !ledState;
digitalWrite(LED_PIN, ledState); ledBlinkTime = currentTime;
}
}

// Actualización pantalla OLED
void updateDisplay() {
if (millis() - displayUpdate < 100) return; // Aumentar frecuencia de actualización

### SMART CANE

Critical Design Document

Revision 0.1

displayUpdate = millis();

if (tempMessage != "" && (millis() - tempMessageStart < TEMP_MESSAGE_DURATION * 10)) { // Duración extendida a 5 segundos
display.clearDisplay();
display.setTextSize(2);
int16_t x1, y1;
uint16_t w, h;
display.getTextBounds(tempMessage, 0, 0, &x1, &y1, &w, &h);
int16_t x = (SCREEN_WIDTH - w) / 2;
int16_t y = (SCREEN_HEIGHT - h) / 2;
if (tempMessageBlink && ((millis() / 500) % 2 == 0)) { // Parpadeo cada 500 ms display.setTextColor(WHITE);
display.setCursor(x, y);
display.println(tempMessage);
} else if (tempMessageBlink) {
display.setTextColor(BLACK); // Apagar texto durante parpadeo display.setCursor(x, y);
display.println(tempMessage);
}
display.display();
return;
}

display.clearDisplay();
display.setTextSize(1);
display.setTextColor(WHITE);

display.setCursor(0, 0);
display.print("Estado: "); display.println(getStateName(currentState));

display.setCursor(0, 15);
display.print("Triggers: ");
display.println(String(triggerCount) + "/" + String(totalSensors));

display.setCursor(0, 25);
display.print("Impacto: ");
display.println(sensors.impact ? (impactTrigger.active ? "Activo" : "OK") : "N/A");

display.setCursor(0, 35);
display.print("MPU: ");
display.println(sensors.mpu ? (mpuTrigger.active ? "Caida" : "OK") : "N/A");

### SMART CANE

Critical Design Document

Revision 0.1

display.setCursor(0, 45);
if (sensors.heart && stableBeatAvg > 0) { drawHeartIcon(0, 45);
display.setCursor(20, 45); display.print(stableBeatAvg); display.print(" BPM");
} else {
display.print("BPM: ");
display.println(sensors.heart && heartTrigger.active ? "Sin señal" : "N/A"); }

display.setCursor(0, 55);
display.print("PIR: ");
display.println(sensors.pir ? (pirTrigger.active ? "Sin mov" : "Mov") : "N/A");

display.display();
}

String getStateName(State state) {
switch (state) {
case CALIBRATING: return "Calibrando"; case NORMAL: return "Normal";
case ALERT_1: return "Alerta 1";
case ALERT_2: return "Alerta 2";
case ALERT_3: return "Alerta 3";
case CRITICO: return "Critico";
case CANCELLED: return "Cancelado"; default: return "Desconocido";
}
}

void printDebugInfo() {
Serial.println("--- Estado del Sistema ---");
Serial.println("Estado: " + getStateName(currentState));
Serial.println("Triggers: " + String(triggerCount) + "/" + String(totalSensors)); Serial.println("Impacto: " + String(sensors.impact ? (impactTrigger.active ? "ACTIVO" : "OK") : "N/A") + " Latch: " + String(impactTrigger.latched));
if (sensors.mpu) {
String mpuStatus = mpuTrigger.active ? "CAIDA" : "OK";
Serial.println("MPU: " + mpuStatus + " State: " + String(mpuState) + " Trigger: " + String(mpuTrigger.active) + " Latch: " + String(mpuTrigger.latched));
} else {

### SMART CANE

Critical Design Document

Revision 0.1

Serial.println("MPU: N/A");
}
Serial.println("BPM: " + String(sensors.heart ? (stableBeatAvg > 0 ? String(stableBeatAvg) + " BPM" : "SIN SEÑAL") : "N/A") + " Latch: " + String(heartTrigger.latched));
Serial.println("PIR: " + String(sensors.pir ? (pirTrigger.active ? "SIN MOV" : "MOV") : "N/A") + " Latch: " + String(pirTrigger.latched));
Serial.println("WiFi: " + String(sensors.wifi ? "Conectado" : "Desconectado"));
}

## 9.0 Test Plan

This test plan will be executed during the Critical Design Review (CDR) to validate the Smart Cane design and ensure its readiness for implementation. It provides a comprehensive assessment of system functionality, performance, and compatibility, addressing both electrical and mechanical aspects to guarantee user reliability and safety.

### 1. Preliminary Test Plan

The preliminary test plan focuses on individual component verification to ensure correct functionality before system integration.

Fall Detection (MPU6050)

- Test the accuracy of acceleration and orientation data.
- Verify detection of simulated falls within 2 seconds.

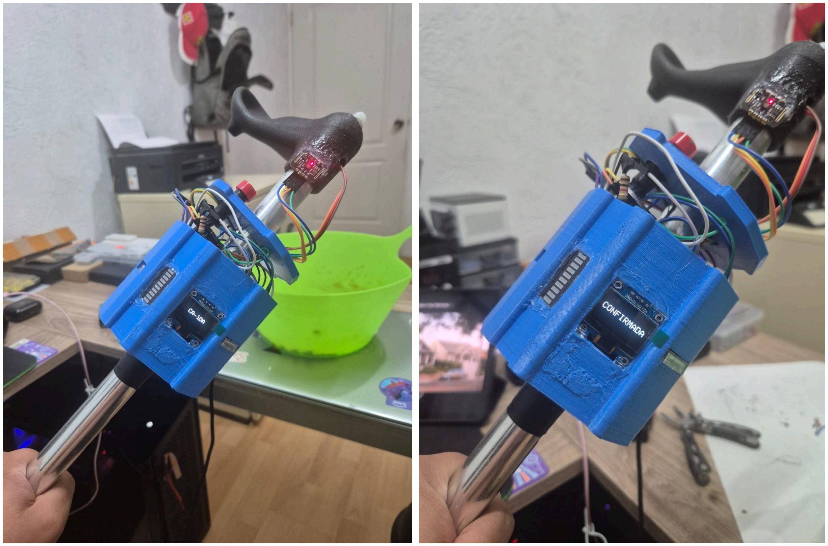
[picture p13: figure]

### SMART CANE

Critical Design Document

Revision 0.1

Heart Rate Monitoring (MAX30102)

- Measure heart rate accuracy (±5 bpm).
- Test disconnection detection and alert activation.

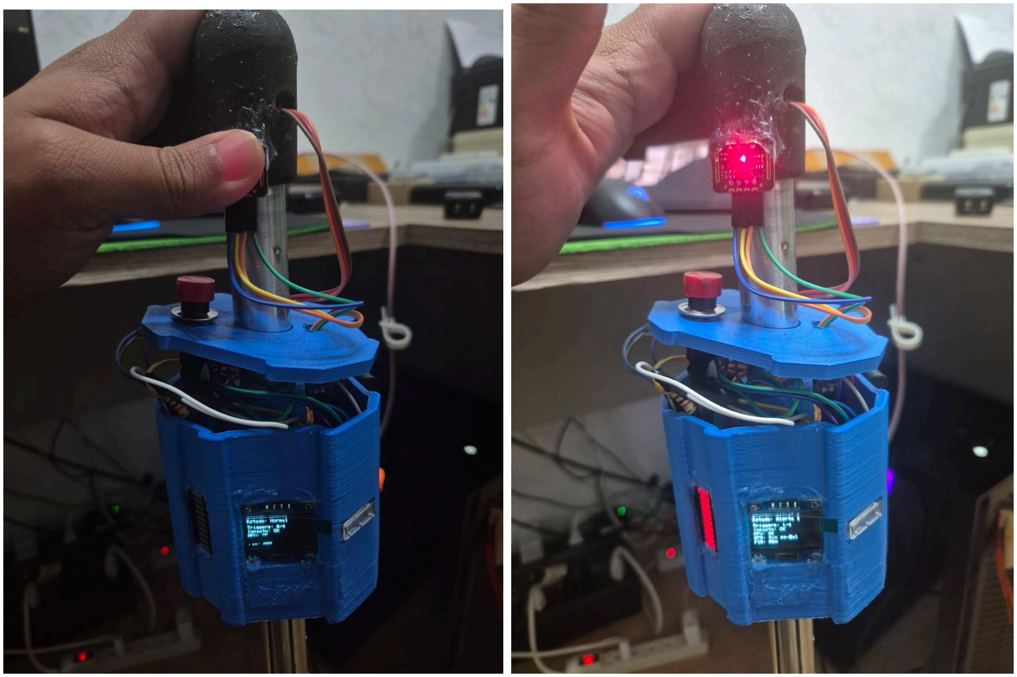
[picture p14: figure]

Inactivity Detection (PIR)

- Simulate inactivity exceeding 5 minutes to trigger alerts.

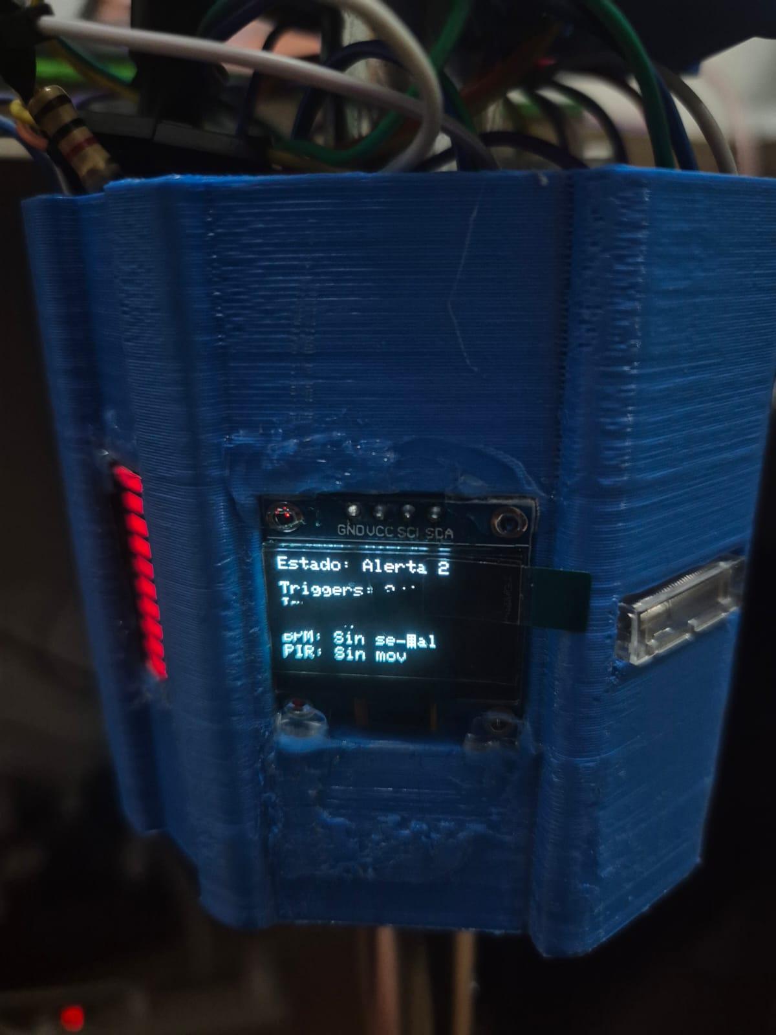
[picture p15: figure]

### SMART CANE

Critical Design Document

Revision 0.1

Impact Detection (KY-031)

- Evaluate sensitivity and response time to impacts.

OLED Display

- Confirm display of heart rate, system state, and alerts.

Buzzer and LED

- Test audible and visual alerts for different activation levels.

“I’m OK” Button

- Verify functionality to cancel false alarms.

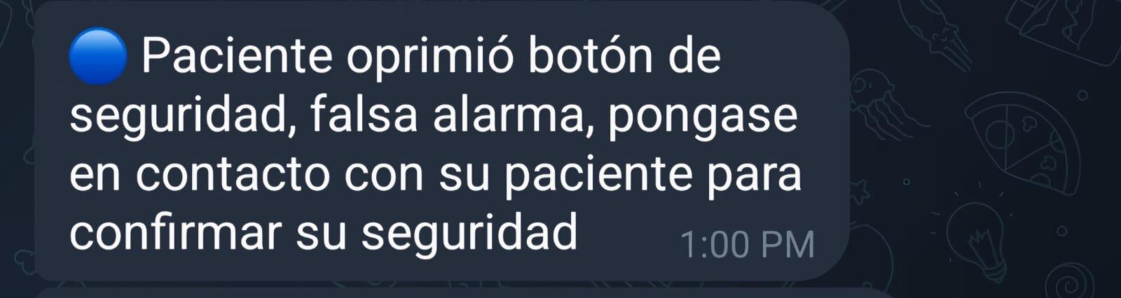
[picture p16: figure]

### 2. Integration and Test Plan

This stage ensures seamless interaction between components and verifies that system performance meets design requirements.

Electrical Functionality and Performance

- Battery Testing: Perform charge/discharge cycles to confirm 12-hour operation.
- Voltage Measurement: Ensure correct output from the power system (EPS).
- EMI Testing: Evaluate resistance to electromagnetic interference.

Software Functionality Tests

- Verify real-time data processing and 1-second screen update intervals.
- Test transitions in the state machine (NORMAL, ALERT_1, etc.).

### SMART CANE

Critical Design Document

Revision 0.1

- Confirm alert transmission via Telegram within 10 seconds of an event.

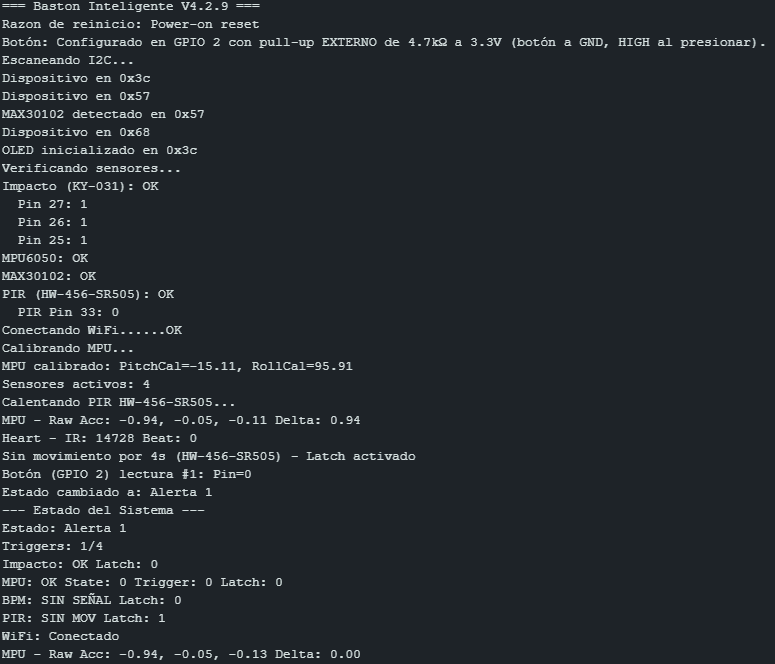
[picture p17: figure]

### SMART CANE

Critical Design Document

Revision 0.1

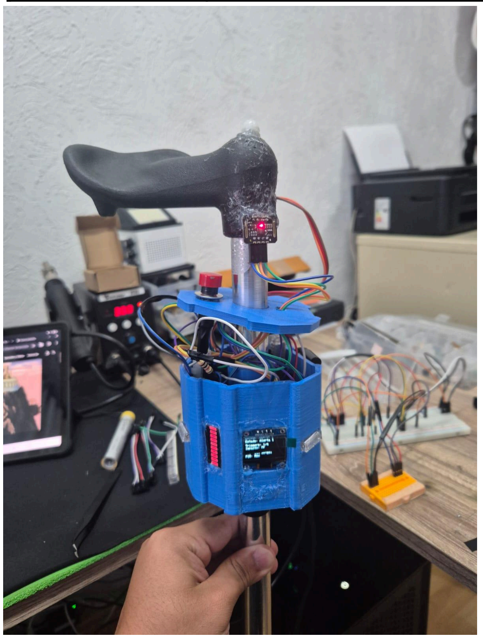
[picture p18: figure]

Mechanical Integration

- Fit Checks: Ensure all components fit within the cane’s housing.
- Cable Routing: Verify cables are organized and do not interfere with components.
- Assembly/Disassembly: Assess ease of maintenance and repair.

### SMART CANE

Critical Design Document

Revision 0.1

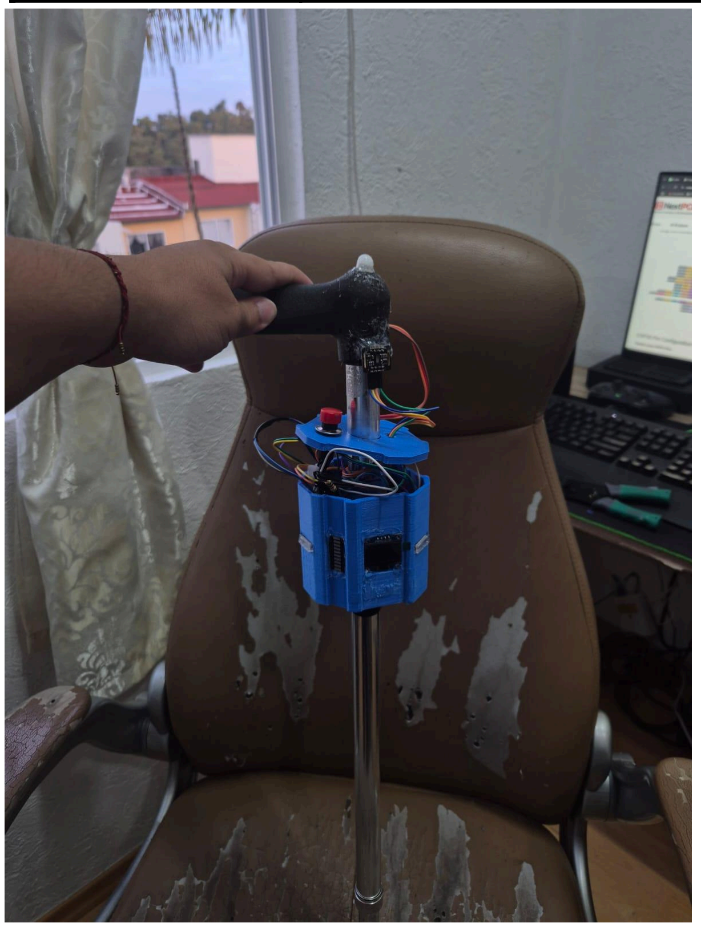
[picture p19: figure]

### 3. System Validation Process

This phase validates that the Smart Cane meets user needs and operates reliably under real-world conditions.

Sensor Range Testing

- Assess detection range of all sensors (e.g., PIR inactivity, BPM).

Repeatability Testing

- Conduct multiple test cycles to ensure consistent performance.

Response Time Testing

- Measure delay between event detection and alert transmission.

### SMART CANE

Critical Design Document

Revision 0.1

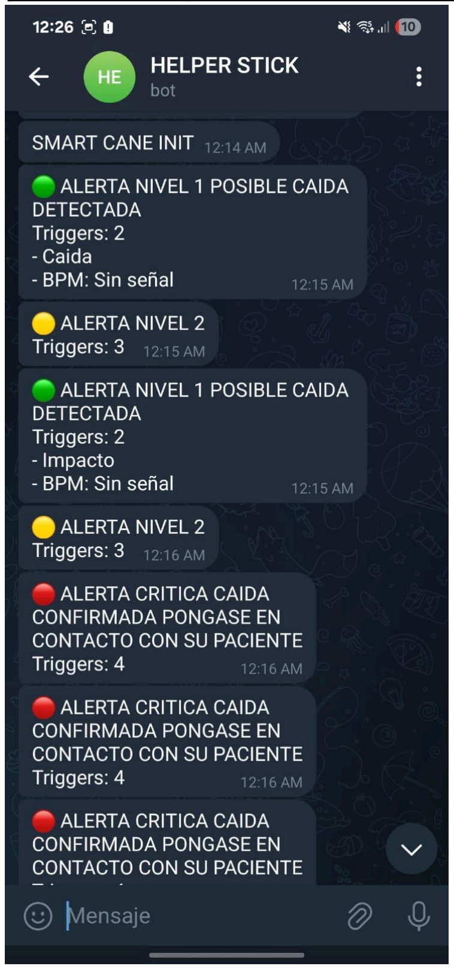
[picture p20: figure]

Environmental Testing

- Operate the cane in temperatures ranging from 0°C to 40°C.

### SMART CANE

Critical Design Document

Revision 0.1

- Test under light rain conditions (IP54 rating).

Safety Testing

- Inspect for absence of exposed electrical components.
- Confirm biocompatibility of surfaces in contact with the user.

User-Centered Testing

- Simulate real-life usage scenarios (e.g., walking, falls).
- Test the effectiveness of the “I’m OK” button to cancel false alarms.

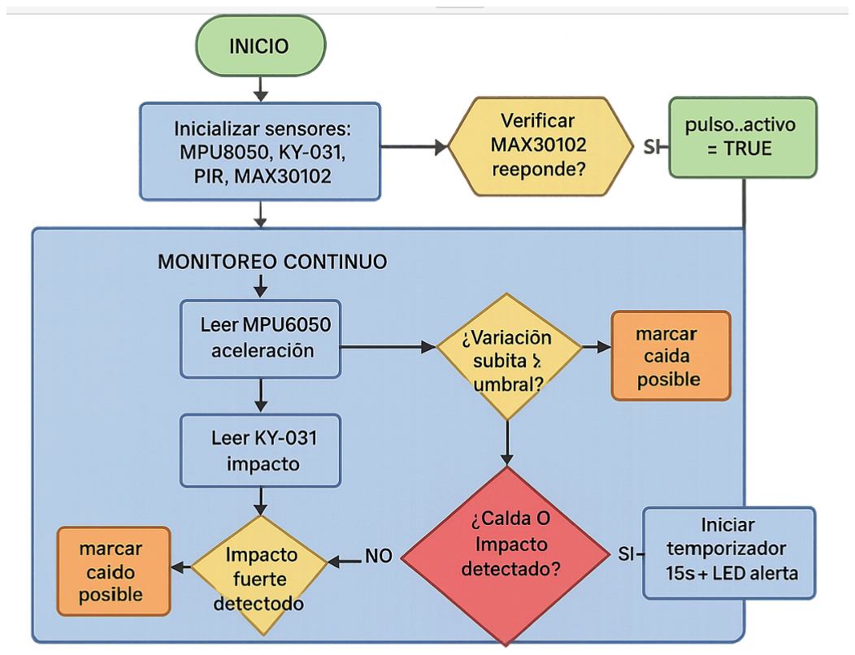
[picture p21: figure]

## 10.0 Glossary

### SMART CANE

Critical Design Document

Revision 0.1

Acronym | Meaning
AT | Assembly Test - A test conducted to verify the correct assembly of the Smart Cane's hardware components before integration.
BPM | Beats Per Minute - A unit measuring heart rate frequency, monitored by the MAX30102 sensor to detect health anomalies.
CDR | Critical Design Review - A formal evaluation to assess the Smart Cane's design maturity and readiness for production.
CoG | Center of Gravity - The point where the Smart Cane's weight is balanced, critical for stability during fall detection design.
CPT | Comprehensive Performance Test - A thorough evaluation of the Smart Cane's overall functionality under various conditions.
EMI | Electromagnetic Interference - External electrical noise that could affect the Smart Cane's sensor accuracy, mitigated by design.
EMC | Electromagnetic Compatibility - The ability of the Smart Cane to operate without causing or suffering from electromagnetic disturbances.
ESP32 | Espressif Systems 32 - The microcontroller (ESP32-WROOM-32) powering the Smart Cane, known for Wi-Fi, dual-core processing, and GPIO flexibility.
FIT | Final Integrated Test - The ultimate test to confirm the Smart Cane's full integration and performance before deployment.
FT | Functional Test - A test to ensure each Smart Cane feature (e.g., fall detection, alerts) works as intended.
GPIO | General Purpose Input/Output - Configurable pins on the ESP32 used to connect sensors and actuators in the Smart Cane.
I2C | Inter-Integrated Circuit - A serial communication protocol used by the ESP32 to interface with the OLED and MPU6050.
ITT | Integrated Test - A test phase where Smart Cane subsystems (sensors, display, communication) are combined and evaluated.

### SMART CANE

Critical Design Document

Revision 0.1

LED | Light Emitting Diode - A visual indicator on the Smart Cane that blinks to reflect trigger status.
LPT | Limited Performance Test - A partial evaluation of the Smart Cane's performance under specific conditions.
PIR | Passive Infrared - The HW-456-SR505 sensor detecting motion or inactivity in the Smart Cane.
PIT | Pre-integrated Test - A preliminary test of Smart Cane components before full system integration.
PT | Post Test - An evaluation conducted after deployment or modifications to assess the Smart Cane's ongoing performance.
PDR | Preliminary Design Review - An initial assessment of the Smart Cane's conceptual design and feasibility.
UPAEP | Universidad Popular Autónoma del Estado de Puebla - The academic institution potentially involved in the Smart Cane project's development.
Wi-Fi | Wireless Fidelity - The wireless networking technology in the ESP32, enabling Telegram alerts in the Smart Cane.

## 11.0 Appendices and/or Annexes

- CIRCUIT FUNCTIONALITY: https://youtu.be/Oy1licVQWoQ

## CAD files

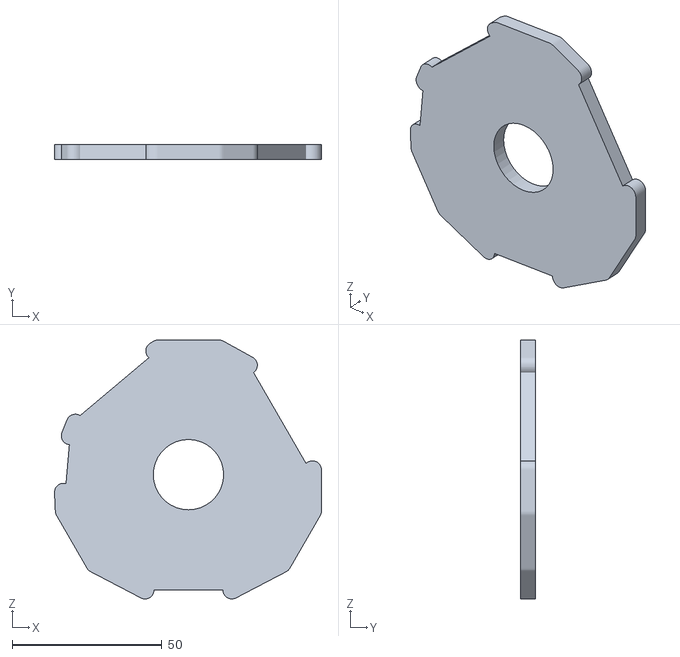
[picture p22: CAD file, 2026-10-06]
3D PRINTS/tapafinal.STL
89.2 x 5.00 x 86.6

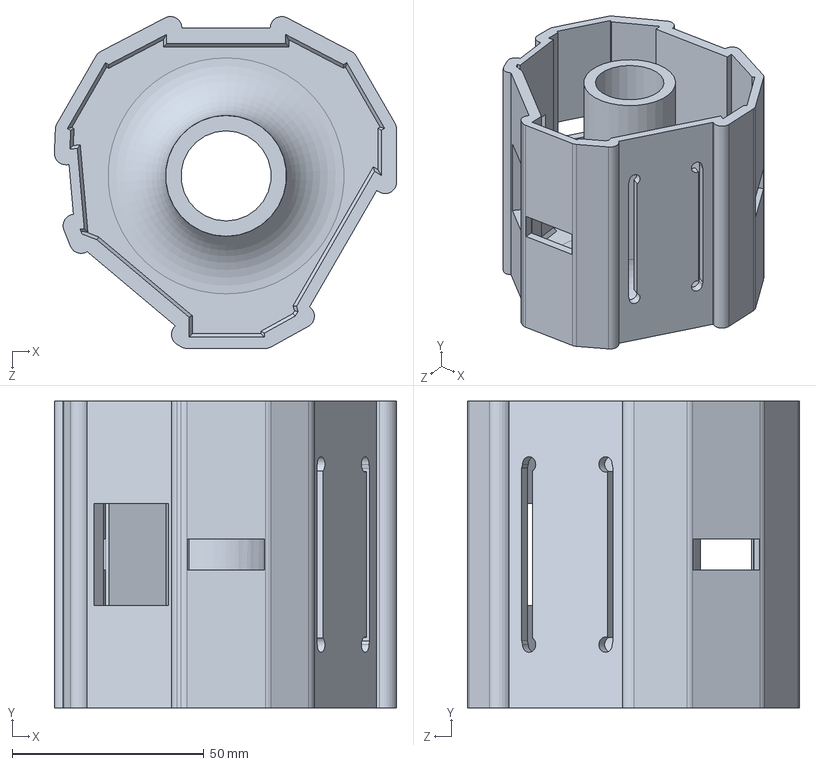
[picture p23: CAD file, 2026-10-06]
CAD/baston final pieza principal.SLDPRT
89.2 x 80.0 x 86.6 mm

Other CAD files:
3D PRINTS/baston final pieza principal.STL

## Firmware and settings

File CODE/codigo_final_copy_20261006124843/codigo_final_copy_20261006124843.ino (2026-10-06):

// ✅ CÓDIGO ACTUALIZADO PARA BASTÓN INTELIGENTE V2.1
// ✅ Con acumulación de triggers, tolerancia a sensores desconectados y mejor gestión de estados
// Incluye: LED como indicador de nivel de alerta, lógica de detección de caídas más robusta, mensajes claros en Serial

#include <Wire.h>
#include <WiFi.h>
#include <WiFiClientSecure.h>
#include <UniversalTelegramBot.h>
#include <MPU6050_tockn.h>
#include <Adafruit_GFX.h>
#include <Adafruit_SSD1306.h>
#include "MAX30105.h"
#include "heartRate.h"

// Pines
#define IMPACT_PIN_1    27
#define IMPACT_PIN_2    26
#define IMPACT_PIN_3    33
#define BUZZER_PIN      25
#define BUTTON_PIN      36
#define PIR_PIN         0
#define LED_PIN         23
#define SDA_PIN         21
#define SCL_PIN         22

// Pantalla
#define SCREEN_WIDTH 128
#define SCREEN_HEIGHT 64
#define OLED_RESET -1
Adafruit_SSD1306 display(SCREEN_WIDTH, SCREEN_HEIGHT, &Wire, OLED_RESET);

// Sensores
MPU6050 mpu(Wire);
MAX30105 particleSensor;

// Telegram
const char* ssid = "***********";
const char* password = "**********";
#define BOT_TOKEN "*********************************"
#define CHAT_ID "***************************"
WiFiClientSecure client;
UniversalTelegramBot bot(BOT_TOKEN, client);

// Estructuras
struct Sensors {
  bool impact1 = false;
  bool impact2 = false;
  bool impact3 = false;
  bool mpu = false;
  bool heart = false;
  bool pir = false;
  bool wifi = false;
};

struct Triggers {
  bool impact1 = false;
  bool impact2 = false;
  bool impact3 = false;
  bool fall = false;
  bool heart = false;
  bool motion = false;
};

Sensors sensors;
Triggers triggers;

// Estados
enum State {
  CALIBRATING,
  NORMAL,
  ALERT_PENDING,
  AWAIT_CONFIRMATION,
  EMERGENCY,
  CANCELLED
};

State currentState = CALIBRATING;

// Variables globales
unsigned long lastMotion = 0;
unsigned long lastTriggerTime = 0;
unsigned long ledTimer = 0;
unsigned long bpmLast = 0;
int triggerCount = 0;
int avgBPM = 0;
int totalFunctionalSensors = 0;
bool ledState = false;
bool heartAvailable = false;
bool mpuCalibrated = false;
float pitchBase = 0, rollBase = 0;
const float accelThreshold = 2.3;
const int BPM_MIN = 45, BPM_MAX = 130;
const unsigned long TIMEOUT_TRIGGER = 10000;
const unsigned long TIMEOUT_CONFIRM = 10000;

void setup() {
  Serial.begin(115200);
  Wire.begin(SDA_PIN, SCL_PIN);
  pinMode(BUZZER_PIN, OUTPUT);
  pinMode(LED_PIN, OUTPUT);
  pinMode(PIR_PIN, INPUT);
  pinMode(BUTTON_PIN, INPUT_PULLUP);
  pinMode(IMPACT_PIN_1, INPUT_PULLUP);
  pinMode(IMPACT_PIN_2, INPUT_PULLUP);
  pinMode(IMPACT_PIN_3, INPUT_PULLUP);

  display.begin(SSD1306_SWITCHCAPVCC, 0x3C);
  display.clearDisplay();
  display.setTextSize(2);
  display.setTextColor(WHITE);
  display.setCursor(10, 10);
  display.println("Calibrando...");
  display.display();

  mpu.begin();
  mpu.calcGyroOffsets(true);
  delay(2000);
  pitchBase = mpu.getAngleX();
  rollBase = mpu.getAngleY();
  mpuCalibrated = true;

  if (particleSensor.begin(Wire, I2C_SPEED_STANDARD)) {
    particleSensor.setup();
    heartAvailable = true;
  }

  connectWiFi();
  currentState = NORMAL;
  Serial.println("Sistema listo");
}

void loop() {
  readSensors();
  updateLED();

  if (digitalRead(BUTTON_PIN) == LOW) {
    Serial.println("Botón presionado. Cancelando alarma.");
    resetTriggers();
    currentState = CANCELLED;
  }

  switch (currentState) {
    case NORMAL:
      if (triggerCount > 0) {
        currentState = ALERT_PENDING;
        lastTriggerTime = millis();
        Serial.println("[ALERTA PENDIENTE] Primer trigger activado");
      }
      break;

    case ALERT_PENDING:
      if (triggerCount >= 2 && millis() - lastTriggerTime > 5000) {
        currentState = AWAIT_CONFIRMATION;
        Serial.println("[ESPERANDO CONFIRMACION] Triggers acumulados: " + String(triggerCount));
      } else if (millis() - lastTriggerTime > 5000) {
        resetTriggers();
        currentState = NORMAL;
        Serial.println("[ALERTA DESCARTADA] Solo un trigger activo");
      }
      break;

    case AWAIT_CONFIRMATION:
      if (triggerCount >= 4) {
        currentState = EMERGENCY;
        Serial.println("[EMERGENCIA DETECTADA]");
        sendAlert();
      } else if (millis() - lastTriggerTime > TIMEOUT_CONFIRM) {
        resetTriggers();
        currentState = NORMAL;
        Serial.println("[CANCELADO] No se acumuló suficiente evidencia");
      }
      break;

    case EMERGENCY:
      digitalWrite(BUZZER_PIN, HIGH);
      break;

    case CANCELLED:
      digitalWrite(BUZZER_PIN, LOW);
      digitalWrite(LED_PIN, LOW);
      resetTriggers();
      currentState = NORMAL;
      break;
  }

  delay(50);
}

void readSensors() {
  triggerCount = 0;

  if (mpuCalibrated) {
    mpu.update();
    float acc = sqrt(pow(mpu.getAccX(), 2) + pow(mpu.getAccY(), 2) + pow(mpu.getAccZ(), 2));
    if (acc > accelThreshold) {
      triggers.fall = true;
      triggerCount++;
    }
  }

  if (digitalRead(IMPACT_PIN_1) == LOW) { triggers.impact1 = true; triggerCount++; }
  if (digitalRead(IMPACT_PIN_2) == LOW) { triggers.impact2 = true; triggerCount++; }
  if (digitalRead(IMPACT_PIN_3) == LOW) { triggers.impact3 = true; triggerCount++; }

  if (heartAvailable) {
    long ir = particleSensor.getIR();
    if (checkForBeat(ir)) {
      long dt = millis() - bpmLast;
      if (dt > 250) {
        bpmLast = millis();
        int bpm = 60.0 / (dt / 1000.0);
        if (bpm > BPM_MAX || bpm < BPM_MIN) {
          triggers.heart = true;
          triggerCount++;
        }
      }
    }
  }

  if (digitalRead(PIR_PIN) == LOW && millis() - lastMotion > 15000) {
    triggers.motion = true;
    triggerCount++;
  } else if (digitalRead(PIR_PIN) == HIGH) {
    lastMotion = millis();
  }
}

void resetTriggers() {
  triggers = Triggers();
  triggerCount = 0;
  Serial.println("Triggers reseteados");
}

void sendAlert() {
  if (WiFi.status() == WL_CONNECTED) {
    String msg = "🚨 CAÍDA DETECTADA 🚨\n";
    msg += "Impactos: ";
    msg += (triggers.impact1 ? "1 " : "");
    msg += (triggers.impact2 ? "2 " : "");
    msg += (triggers.impact3 ? "3 " : "");
    msg += "\nMPU: ";
    msg += (triggers.fall ? "✔️" : "✖️");
    msg += "\nBPM: ";
    msg += (triggers.heart ? "Anómalos" : "OK");
    msg += "\nMovimiento: ";
    msg += (triggers.motion ? "NO" : "Sí");
    bot.sendMessage(CHAT_ID, msg, "");
  }
}

void updateLED() {
  int freq = triggerCount * 2;
  if (freq == 0) {
    digitalWrite(LED_PIN, LOW);
    return;
  }

  if (millis() - ledTimer > 1000 / freq) {
    ledState = !ledState;
    digitalWrite(LED_PIN, ledState);
    ledTimer = millis();
  }
}

void connectWiFi() {
  WiFi.begin(ssid, password);
  int t = 0;
  while (WiFi.status() != WL_CONNECTED && t < 20) {
    delay(500);
    Serial.print(".");
    t++;
  }
  if (WiFi.status() == WL_CONNECTED) {
    client.setInsecure();
    Serial.println("\nWiFi conectado: " + WiFi.localIP().toString());
    bot.sendMessage(CHAT_ID, "🟢 Sistema listo", "");
  } else {
    Serial.println("\n❌ Sin conexión WiFi");
  }
}
